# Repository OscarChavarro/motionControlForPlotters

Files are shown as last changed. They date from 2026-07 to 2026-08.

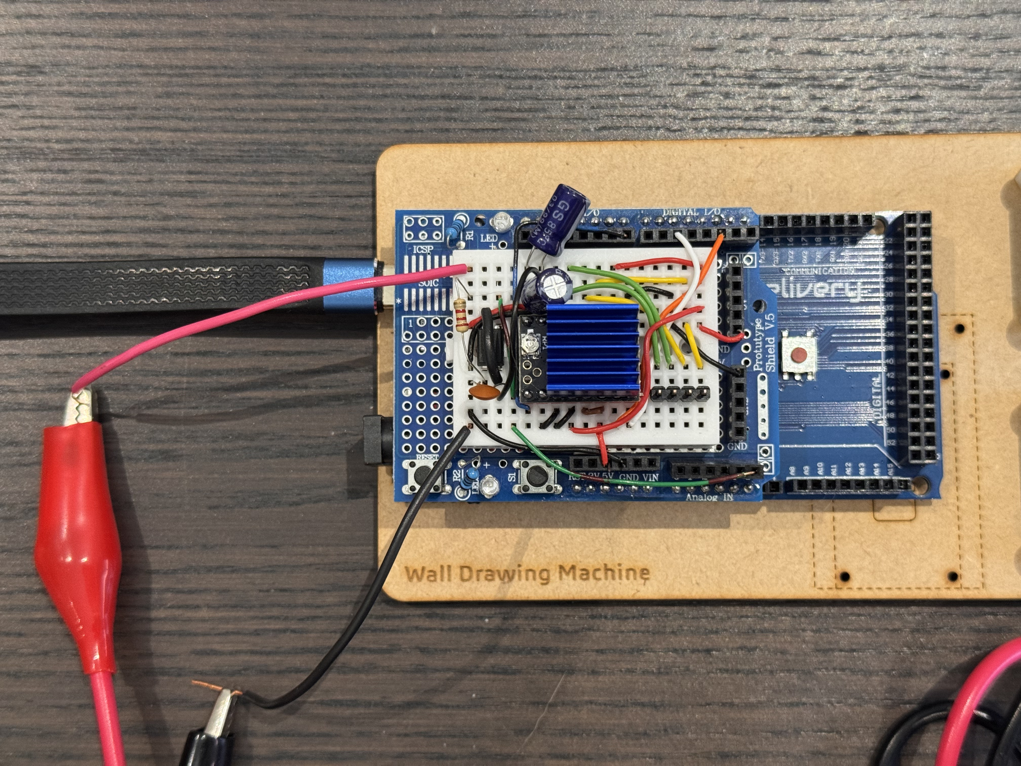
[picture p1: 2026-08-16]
platform/arduinoStepMotorsXYController/doc/prototypeShield.jpg

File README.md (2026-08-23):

# Motion Control for Plotters

Motion Control for Plotters is a firmware-oriented C++ project for building a portable motion-control core and platform-specific embedded targets for plotter hardware. The portable core and AVR target use C++17; the ESP32 target uses C++20.

The current codebase is split into two main areas:

- `motionControlCore`: reusable platform-independent motion logic.
- `platform`: hardware-specific firmware entry points and device wrappers.

At this stage, the core contains 2D rasterization, stepper-motor modeling, and a portable per-motor controller. The Arduino AVR target supplies the hardware clock, UART, power-supply sensing, and `STEP`/`DIR` pulse generation. The ESP32 target supplies a BLE serial endpoint that will later control servos. The Arduino's current repeating movement is a diagnostic program that will evolve into the generic controller.

## Core

`motionControlCore` currently provides:

- `Rasterizer2D`, a callback-based rasterization utility intended for plotter-oriented motion code.
- `StepperMotor`, the physical motor model and unit conversions between microsteps, rotations, and degrees.
- `StepperMotorController`, independent position, direction, speed, and trapezoidal-profile state for one motor.
- `StepperMotorDriver`, the platform boundary used by the controller to select direction and emit a step.
- `SystemClock`, `UartSerial`, `GpioLed`, and `ExternalPowerSupplyDetector`, portable HAL interfaces implemented by each target platform.

`UartSerial` also contains the reusable integer, fixed-point, voltage, and line
formatting used by telemetry. Platform implementations only provide UART
initialization and character input/output.

It supports:

- Drawing integer 2D lines with a Bresenham-style algorithm.
- Drawing polygon outlines by rasterizing each polygon edge.
- Filling polygons by emitting horizontal spans through a callback.

The rasterizer does not draw into a framebuffer. Instead, callers provide callbacks that receive generated points or spans. This keeps the core independent from any display, image, or hardware implementation and makes it suitable for later connection to motion planners, step schedulers, or other plotter backends.

## Platform

The implemented platform targets are:

- `platform/arduinoStepMotorsXYController`, AVR firmware built without the
  Arduino IDE.
- `platform/esp32ServoBLEController`, C++20 ESP-IDF firmware for an ESP-WROOM-32
  development board. It exposes a Nordic UART Service over BLE and only uses
  USB for flashing.

The Arduino target's platform-specific C++ code lives directly under `platform/arduinoStepMotorsXYController/src`.

It provides:

- `AvrSystemClock`: implements `SystemClock` using AVR Timer0 compare interrupts.
- `AvrUartSerial`: implements the primitive `UartSerial` operations using UART0.
- `AvrGpioLed`: implements `GpioLed` using the built-in board LED registers.
- `AvrExternalPowerSupplyDetector`: implements external motor-supply sensing through AVR ADC0.
- `AvrStepDirectionDriver`: maps Arduino digital pins to AVR registers and generates `STEP`/`DIR` signals.
- `main.cpp`: constructs AVR implementations, exposes them to the program through HAL references, declares the motor registry, and runs the current diagnostic motion program.

Adding a motor requires adding one entry to `STEPPER_MOTOR_PROGRAMS` in
`main.cpp`. The number of motors and all runtime arrays are derived from that
single registry. Every entry can use a different model, pin pair, electrical
timing, travel distance, and acceleration/cruise/deceleration times.

On the Mega 2560, the AVR driver supports digital pins D2-D53. With D0/D1
reserved for USB UART, this gives a theoretical wiring limit of 26 two-pin
motor drivers. Actual simultaneous motor count and speed remain constrained by
the current cooperative pulse generator and the 16 MHz CPU; timer-driven pulse
scheduling is a later phase.

Supported board presets are:

- `uno`
- `nano`
- `mega2560`

## Install

Prerequisites:

- CMake 3.22 or newer.
- `avr-gcc`.
- AVR binutils and runtime libraries.
- `avrdude` for uploading firmware to an Arduino board.
- `make` or another CMake-supported build tool.
- ESP-IDF 5.x and its ESP32 toolchain for the optional ESP32 firmware.

macOS:

```bash
brew tap osx-cross/avr;brew trust --formula osx-cross/avr/avr-gcc@9;brew trust osx-cross/avr;brew install avr-gcc avrdude
```

Ubuntu Linux:

```bash
sudo apt-get update
sudo apt-get install cmake gcc-avr avr-libc binutils-avr avrdude make
```

## Build

Configure the project from the repository root:

```bash
cmake -S . -B build
```

Build the reusable core and configure/build the Arduino firmware:

```bash
cmake --build build --target arduino_build
```

Generate the Arduino Intel HEX firmware:

```bash
cmake --build build --target arduino_hex
```

The generated firmware is written to:

```text
build/platform-arduinoStepMotorsXYController/arduinoStepMotorsXYController.hex
```

Build the ESP32 BLE firmware after activating ESP-IDF:

```bash
cmake --build build --target esp32_build
```

The ESP-IDF target defaults to `esp32`. Select another supported family member
when configuring the repository, for example:

```bash
cmake -S . -B build-h2 -DIDF_TARGET=esp32h2
cmake --build build-h2 --target esp32_build
```

You can also run
`platform/esp32ServoBLEController/scripts/compile.sh` directly. See that
platform's README for its BLE service UUIDs and setup details.

## Upload

Connect the Arduino board and configure the serial port if needed:

```bash
cmake -S . -B build -DARDUINO_BOARD=uno -DARDUINO_PORT=/dev/ttyACM0
cmake --build build --target arduino_upload
```

On macOS, the port will commonly look like `/dev/cu.usbmodem...` or `/dev/cu.usbserial...`.

Flash the ESP32 firmware through its temporary USB connection with:

```bash
cmake --build build --target esp32_flash
```

## Serial Monitor

Open the serial monitor through the CMake target:

```bash
cmake --build build --target arduino_monitor
```

The monitor target uses `pyserial` miniterm when available, then falls back to `picocom` or the repository's shell serial monitor.

## Configuration

The top-level CMake project exposes these platform options:

- `IDF_TARGET`: ESP-IDF target used by the BLE firmware (default `esp32`;
  for example, `esp32h2`).

- `ARDUINO_BOARD`: board preset, one of `uno`, `nano`, or `mega2560`.
- `ARDUINO_PORT`: serial/upload port.
- `ARDUINO_UPLOAD_BAUD`: optional upload baud override.
- `ARDUINO_MONITOR_BAUD`: optional serial monitor baud override.
- `ARDUINO_PROGRAMMER`: optional `avrdude` programmer override.
- `STEPPER_MOTOR_STEP_PIN`: X-axis diagnostic motor `STEP` pin (default D2).
- `STEPPER_MOTOR_DIRECTION_PIN`: X-axis diagnostic motor `DIR` pin (default D5).
- `STEPPER_MOTOR_Y_STEP_PIN`: Y-axis FS31W01 `STEP` pin (default D3).
- `STEPPER_MOTOR_Y_DIRECTION_PIN`: Y-axis FS31W01 `DIR` pin (default D6).
- `STEPPER_MOTOR_Y_DIRECTION_INVERTED`: inverts the Y `DIR` output in
  firmware (default `0`), without swapping motor wires.
- `STEPPER_MOTOR_Y_FULL_STEPS_PER_ROTATION`: Y-axis motor resolution in full
  steps (default 200).
- `STEPPER_MOTOR_Y_TRAVEL_ROTATIONS`: rotations for one direction of the Y
  test profile (default 2, matching X).
- `STEPPER_MOTOR_TRAVEL_ROTATIONS`: rotations in each forward/backward segment.

The Arduino subproject also accepts lower-level overrides such as `ARDUINO_MCU` and `ARDUINO_F_CPU` when a preset is not enough.

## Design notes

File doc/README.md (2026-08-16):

# Motion Control Platform Architecture Notes

## Project Vision

This project is not intended to be an Arduino sketch or a GRBL clone. The objective is to build a portable, modular motion-control framework capable of running on multiple embedded platforms while being driven by a sophisticated CAD backend.

Primary goals:

- C++-based architecture.
- No Arduino IDE.
- Git repository with CLI workflow.
- Portable core.
- Hardware Abstraction Layer (HAL).
- Binary communication protocol.
- Interrupt- and timer-based execution (no `delay()`).
- Closed-loop validation using computer vision.

## Target Platforms

- Arduino AVR (Mega/Uno family)
- ESP32
- Linux-based dual-core RISC-V development board (64 MB RAM)

The same motion core should execute on every platform, with only the HAL changing.

# Multiple device system

Every firmware integrated with the interactive console must implement the
`device` serial command. It must return exactly one line in this format:

```text
Device <hardware description>, Role <firmware role>
```

The hardware description identifies the board or hardware on which the
firmware runs. The role identifies the responsibility provided by that
firmware. For example, the current Arduino controller returns:

```text
Device arduino ATmega2650, Role XY steper motor controller
```

When started through `./scripts/runInteractive.sh`, the interactive console
enumerates all available USB serial ports, opens each one, and sends `device`.
It retains the connections that provide a valid device description and starts
only when it finds the expected device and role. If no expected firmware is
found, it exits with an English error message. This discovery contract allows
future console features to communicate with several role-specific devices at
the same time.

## Current Implementation Phase

The repository is currently building the infrastructure incrementally. The
Arduino program is diagnostic firmware, not the final motion-control protocol
or planner. Its repeating forward/backward movement exists to exercise motor
modeling, physical pin assignment, motion profiles, power gating, and
telemetry while those pieces are separated into reusable layers.

The current boundary is:

```text
main.cpp motor registry and diagnostic program
    -> portable HAL interfaces
        -> SystemClock, UartSerial, GpioLed,
           ExternalPowerSupplyDetector, StepperMotorDriver
    -> portable motion logic
        -> StepperMotorController (per-motor state and motion profile)
    -> AVR implementations created during platform initialization
        -> AvrSystemClock, AvrUartSerial, AvrGpioLed,
           AvrExternalPowerSupplyDetector, AvrStepDirectionDriver
```

The diagnostic program constructs each concrete `Avr*` object once and then
uses references to the corresponding core interface. This keeps application
logic independent from AVR headers and allows another platform to compose the
same logic with its own implementations.

`StepperMotor` describes one physical motor installation: motor reference,
motor type, full steps per rotation, configured microstepping, and its `STEP`
and `DIR` pin assignment. Each registered motor owns an independent driver and
controller state, including position, direction, speed, profile clock, and
fractional-step accumulator.

On an Arduino Mega 2560, reserving D0 and D1 for UART leaves D2-D53 available
for up to 26 two-pin `STEP`/`DIR` motor drivers. The AVR platform driver maps
that complete digital-pin range. This is a pin-count limit only: the present
cooperative loop emits pulses with short blocking waits. A timer/interrupt
step scheduler is still required before simultaneous high-rate operation can
be guaranteed for many motors.

## Development Environment

- VS Code
- PlatformIO for embedded builds
- Git
- C++
- Optional CMake for the reusable core

Suggested repository layout:

```text
motion-core/
firmware-avr/
firmware-esp32/
firmware-riscv/
host/
docs/
tests/
```

The reusable motion core should remain independent from PlatformIO.

## Motion Architecture

```text
CAD Kernel
    ↓
Hidden Line Removal
    ↓
Motion Backend
    ↓
Binary Protocol
    ↓
Motion Controller
    ↓
Motion Planner
    ↓
Rasterization (Bresenham)
    ↓
Step Scheduler
    ↓
HAL
    ↓
Stepper Drivers
```

## PC Responsibilities

The PC already implements:

- Winged-edge B-Rep kernel
- Euler operators
- Splitting operations
- Boolean operations
- Camera projection
- Quantitative observability
- Appel hidden-line algorithm

The CAD kernel generates projected 2D primitives that will drive the plotter.

The firmware never manipulates CAD topology.

## Firmware Responsibilities

The firmware is responsible for:

- Parsing binary packets
- Queueing primitives
- Motion planning
- Rasterization
- Pulse generation
- Sensor handling
- Safety

## Primitive-Based Protocol

The protocol transports graphical primitives rather than low-level motor commands.

Examples:

- MOVE_TO
- LINE_TO
- ARC
- BEZIER
- PEN_UP
- PEN_DOWN
- HOME
- STOP
- PANIC

The protocol is binary, versioned, little-endian, and transport-independent (USB, TCP, BLE, Wi-Fi, UART).

Each command should include a transaction ID to correlate firmware execution with camera observations.

## Rasterization

The firmware should execute Bresenham internally.

Curves should be converted into line segments before Bresenham.

Examples:

Bezier
→ Adaptive subdivision
→ Line segments
→ Bresenham

Arc
→ Arc subdivision
→ Line segments
→ Bresenham

## Motion Generation

The firmware should use:

- Hardware timers
- Interrupts
- State machines
- Pulse scheduling

The final scheduler must not use blocking delays. The current diagnostic AVR
driver still uses short blocking waits while emitting each pulse; replacing it
with timer/interrupt scheduling is part of the planned platform work.

Future extensions:

- Command-driven trapezoidal profiles (a repeating diagnostic profile exists)
- S-curve acceleration
- Look-ahead planner

## Safety

Firmware states:

- BOOT
- INITIALIZING
- IDLE
- READY
- RUNNING
- PAUSED
- HOMING
- ERROR
- PANIC

PANIC immediately:

- Stops motion timers
- Clears queues
- Disables drivers
- De-energizes motors

Recovery requires RESET followed by HOMING.

## Limit Switches

Support:

- Home switches
- Safety switches
- Probe inputs
- Soft limits

Soft limits should exist both in the PC and firmware.

## Events

Firmware should report binary events instead of text:

- READY
- HOME_COMPLETE
- MOTION_COMPLETE
- LIMIT_REACHED
- EMERGENCY_STOP
- PANIC
- POSITION_LOST

## Closed-Loop Vision

Unlike traditional CNC controllers, this project includes vision-based validation.

The PC contains:

- OpenCV
- High-speed camera
- AprilTag fiducial tracking

Workflow:

1. PC sends a primitive.
2. Firmware executes it.
3. Camera measures the physical position.
4. PC validates the result.
5. PC either:
   - continues,
   - sends a correction,
   - retries,
   - or enters PANIC mode.

This creates a distributed control system where the firmware guarantees deterministic execution while the PC closes the feedback loop through computer vision.

## Long-Term Goal

Develop a modern, portable motion-control platform that cleanly separates:

- CAD
- Communication
- Motion planning
- Hardware abstraction
- Safety
- Vision feedback

The architecture should scale from AVR to ESP32 and Linux-based RISC-V systems without changing the core motion logic.

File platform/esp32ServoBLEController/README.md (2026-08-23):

# ESP32 Servo BLE Controller

ESP-IDF firmware for ESP32-family devices with Bluetooth Low Energy support.
The default target is the classic dual-core ESP32 development board based on
the ESP-WROOM-32 module (including the AZDelivery clone). USB is only used to
flash the firmware. Runtime communication uses Bluetooth Low Energy.

The device name is `ESP-WROOM-32` and it implements the Nordic UART Service
(NUS). GPIO2 also drives a status LED, alternating between one second off and
one second on while the firmware is running. GPIO22 is configured as a 50 Hz
LEDC PWM output for the connected servo; `motorPosition` values from 0 to 255
are mapped to 1000 us to 2000 us servo pulses.

| Purpose | UUID | Properties |
|---|---|---|
| Service | `6E400001-B5A3-F393-E0A9-E50E24DCCA9E` | Primary service |
| Client to ESP32 (RX) | `6E400002-B5A3-F393-E0A9-E50E24DCCA9E` | Write, write without response |
| ESP32 to client (TX) | `6E400003-B5A3-F393-E0A9-E50E24DCCA9E` | Notify |

After connecting, the client must subscribe to TX notifications. The firmware
then sends `firmware boot`. Bytes written to RX are parsed as ASCII commands;
clients can send one complete command per BLE write or terminate streamed
commands with `\r` or `\n`. Long output is split into chunks that fit the
negotiated BLE ATT MTU.

Initial BLE commands:

```text
hardware
. [<id>]
servo <id> <position>
test off|on
```

`hardware` lists the GPIO22 servo PWM output and the GPIO2 heartbeat LED.
`.` prints the current servo telemetry summary. `. 0` prints the CSV status
for the servo PWM element and `. 1` prints the CSV status for the heartbeat
LED element. `servo 0 <position>` sets the servo resource to a value from 0 to
255 and disables the demo movement. `test off` stops the demo movement, while
`test on` enables it again.

## Requirements

- ESP-IDF 5.x with the toolchain for the selected `IDF_TARGET` installed
- CMake 3.22 or newer
- Ninja
- An FTDI UART adapter and a stable board power source for the current hardware

The scripts automatically discover installations made by EIM under
`~/.espressif`, common legacy installations under `~/esp/esp-idf` and
`~/esp-idf`, or an SDK selected explicitly through `IDF_PATH`.

## Build

From this directory:

```bash
./scripts/compile.sh
```

`IDF_TARGET` defaults to `esp32`. Set it to build for another supported chip;
each target uses a separate build directory and SDK configuration:

```bash
IDF_TARGET=esp32h2 ./scripts/compile.sh
```

From a configured repository root build, the equivalent target is:

```bash
cmake --build cmake-build-host-debug --target esp32_build
```

For a repository-level build, select the target while configuring CMake:

```bash
cmake -S . -B cmake-build-h2 -DIDF_TARGET=esp32h2
cmake --build cmake-build-h2 --target esp32_build
```

The BLE task uses core 1 on multicore configurations and no explicit affinity
on single-core configurations. GPIO2 remains the default status LED pin; board
variants whose onboard LED uses another GPIO still require a pin adjustment.

## Flash through USB

The current board's onboard CP210x bridge is damaged. Connect an FTDI adapter
to UART0 RX/TX and use `/dev/cu.usbserial-1120`. Cross the data lines (ESP32 TX0
to FTDI RX and ESP32 RX0 to FTDI TX), connect their grounds, and power the ESP32
from a stable source. Do not rely on a small FTDI adapter's 3.3 V output to
power the board.

The damaged USB/reset circuitry on this particular board also makes its RST
button unreliable: EN measures about 3.28 V at rest but only falls to about
1.3 V while RST is held. A valid manual reset is obtained by briefly connecting
EN directly to GND and then releasing it.

An external normally-open reset button can be installed as follows. The button
must connect EN to GND, never directly to 3.3 V. The capacitor is optional; if
the damaged automatic-reset branch continues driving EN, isolate that branch
before adding a stronger pull-up.

```text
                         ESP32
  +3.3 V ----[ 4.7 kΩ ]----+---- EN / CHIP_PU
                            |
                            +----||---- GND
                            |   100 nF
                            |
                         [ RESET ]
                      normally open
                            |
                           GND
```

To enter the immutable ROM bootloader:

1. Connect GPIO0 to GND.
2. Briefly connect EN to GND, then release EN.
3. Keep GPIO0 low while the flash tool connects and performs its operations.
4. Run the flash command below.

```bash
./scripts/send.sh /dev/cu.usbserial-1120
```

The script builds the project, writes the bootloader, partition table and
application, and then runs an independent `verify_flash` comparison against all
three generated binaries. A successful operation contains three `verify OK
(digest matched)` messages. It deliberately finishes with `--after no_reset`
so this board remains in the ROM bootloader instead of using its unreliable
reset circuitry. The default transfer rate is the conservative 115200 baud
because this board stopped responding during a 460800-baud transfer. Set
`ESP32_BAUD` explicitly only when using a known-stable UART connection. The
script also waits indefinitely for the manual ROM synchronization by default;
set `ESP32_CONNECT_ATTEMPTS` to a positive value to impose a retry limit.
Both write and verification use `--before no_reset`; EN and GPIO0 must be
operated manually because DTR/RTS reset sequences are unreliable on this board.

After verification, disconnect GPIO0 from GND, remove power for at least two
seconds, and restore power. A cold power cycle has been more reliable than the
board's RST button. A normal UART boot starts with:

```text
boot:0x13 (SPI_FAST_FLASH_BOOT)
```

The following output means GPIO0 was sampled low and the application will not
run:

```text
boot:0x3 (DOWNLOAD_BOOT...)
waiting for download
```

Repeated `rst:0x1 (POWERON_RESET)` messages indicate instability on EN or the
power/reset circuitry rather than a firmware crash.

Set `ESP32_PORT=/dev/...` or pass the port as the first argument to avoid
interactive port selection:

```bash
./scripts/send.sh /dev/cu.usbserial-0001
```

For non-`esp32` targets, the script selects the matching esptool chip, uses the
target-generated flash layout, and enables normal automatic reset handling:

```bash
IDF_TARGET=esp32h2 ./scripts/send.sh /dev/cu.usbmodem0001
```

The equivalent root target is `esp32_flash`. Disconnecting USB after flashing
does not affect BLE operation as long as the board has another power source.

## Hardware diagnosis from the MicroPython test

The following facts were verified on this specific board during bring-up:

- The chip is an ESP32-D0WDQ6 revision 1.0 with two cores and 4 MB of flash.
- The ROM bootloader, SPI flash and UART0 work. Written images passed an
  independent digest comparison against the source binaries.
- MicroPython 1.28.0 booted successfully and reached its UART REPL.
- A minimal `main.py` could drive GPIO2 high and blink an attached LED once it
  was explicitly started.
- GPIO2 read back as high and illuminated the LED, so the pin and LED wiring
  are operational.
- A cold power cycle with GPIO0 high produced `SPI_FAST_FLASH_BOOT` and allowed
  MicroPython to start `main.py` automatically.
- The unreliable EN/RST and GPIO0 boot-strapping behavior explains the earlier
  failures to observe either the GPIO2 heartbeat or BLE advertisements. Those
  failures do not by themselves implicate FreeRTOS, NimBLE or the C++ image.

At the end of this diagnostic test, MicroPython occupies the flash and the C++
firmware must be flashed again before testing BLE.

## Returning to the C++ firmware

Flashing the C++ image will overwrite MicroPython, including its filesystem and
`main.py`. This does not remove the ESP32 ROM bootloader: the ROM loader is part
of the chip and remains available regardless of what is stored in SPI flash.
Therefore a broken or non-booting C++ application can always be replaced by
entering download mode with GPIO0 and EN as described above.

Use this recovery and activation plan:

1. Build the C++ firmware with `./scripts/compile.sh`.
2. Enter the ROM bootloader using GPIO0 and a direct EN-to-GND reset.
3. Run `./scripts/send.sh /dev/cu.usbserial-1120` and require all three
   `verify OK` results before proceeding.
4. Disconnect GPIO0 from GND.
5. Remove power for at least two seconds and restore it; do not depend on the
   faulty RST button or on `esptool run` to launch the application.
6. Confirm the GPIO2 one-second heartbeat first, then scan for the BLE device
   name and Nordic UART Service UUID.
7. If the heartbeat is absent, capture UART0 during another cold power cycle.
   Diagnose the ROM boot mode before changing any C++ or FreeRTOS code.

## Clean

```bash
./scripts/clean.sh
```

This removes the ESP-IDF build tree plus generated `sdkconfig` files. The root
CMake target is `esp32_clean`.

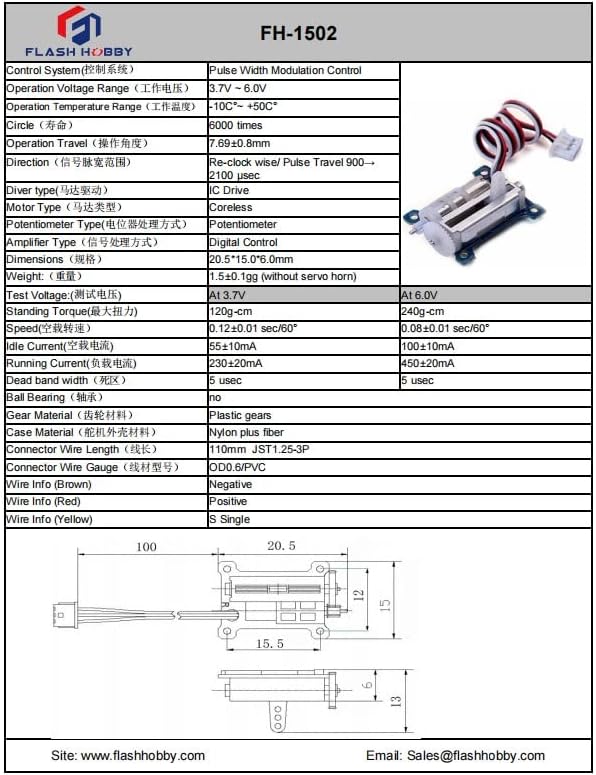
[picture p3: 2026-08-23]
doc/references/electronicsElements/motors/flashHobby_FH1502.jpg

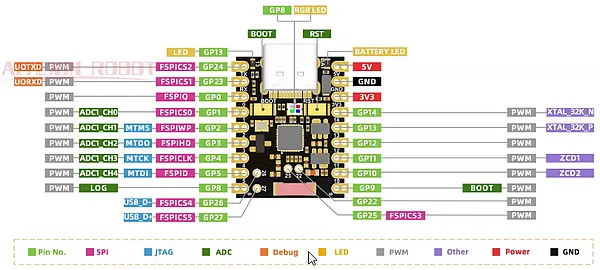
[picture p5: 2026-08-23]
doc/references/electronicsElements/microControllerBoards/esp32_h2.png

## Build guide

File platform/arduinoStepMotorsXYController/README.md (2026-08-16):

# Arduino Step Motors XY Controller

Firmware target for an Arduino UNO or Mega2560-based XY step motor controller.

# Elements used

## Artillery D42HSA5401-23B stepper motor

NEMA17 "pancake" bipolar stepper motor, used for the Artillery Sidewinder
X1/X2 and Genius 3D printer extruders.

| Spec | Value |
|---|---|
| Model | D42HSA5401-23B |
| Motor type | NEMA17 bipolar hybrid stepping motor, "pancake" (short body) |
| Step angle | 1.8 degrees (200 steps/revolution) |
| Rated current | 0.8 A |
| Holding torque | 0.12 N.m |
| Shaft diameter | 5.0 mm |
| Body length | 22 mm |

Source: [Artillery Sidewinder X1/X2 Genius Extruder Nema17 Stepper Motor (D42HSA5401-23B)](https://www.amazon.es/Artillery-Sidewinder-Extrusor-Stepper-D42HSA5401-23B/dp/B0B26XPB9P)

## TMC2209 V2.0 stepper driver (generic clone)

Generic "TMC2209 V2.0" driver module, pin-compatible with the A4988/DRV8825
socket footprint, used to replace the A4988 driver.

| Spec | Value |
|---|---|
| Model | TMC2209 V2.0 (generic clone, sold as a 2-piece pack) |
| Driver chip | TRINAMIC/Analog Devices TMC2209 |
| Sense resistor | 0.11 ohm (R110) |
| Max current | 1.77 A RMS at VREF=2.5V (practical modules typically limited to ~1.2 A RMS) |
| Microstepping | Up to 1/256 via MicroPlyer interpolation, MS1/MS2 pins select 1/8, 1/16, 1/32, 1/64 in standalone mode |
| Chopper modes | StealthChop2 (silent) and SpreadCycle, selectable via SPREAD pin |
| Control interface | STEP/DIR, single-wire UART, analog VREF current scaling |

Source: [2 piezas de controladores de motor paso a paso TMC2209 V2.0](https://www.amazon.es/dp/B0D6R7YCRT)

## AZDelivery AZ-MEGA2560 microcontroller board (Arduino Mega 2560 clone)

Arduino Mega 2560-compatible board used as the firmware target.

| Spec | Value |
|---|---|
| Model | AZDelivery AZ-MEGA2560-Board with USB-C |
| Microcontroller | ATmega2560 |
| Flash memory | 256 KB (8 KB used by bootloader) |
| SRAM | 8 KB |
| EEPROM | 4 KB |
| Digital I/O pins | 54 (14 usable as PWM) |
| Analog inputs | 16 |
| UARTs | 4 |
| Clock speed | 16 MHz |
| USB interface | USB-C, CH340 converter |
| External power input | 5.5 x 2.1 mm jack, 6-15V (7-12V recommended) |

Source: [AZDelivery AZ-MEGA2560 Board Mikrokontroller mit USB-C Anschluss](https://www.amazon.es/dp/B0DHY38ZB1)

## LOMVUM T28B digital multimeter

Used for VREF calibration and for driver/motor temperature checks, via its
K-type thermocouple probe.

| Spec | Value |
|---|---|
| Model | LOMVUM T28B |
| Type | Auto-ranging digital multimeter, True RMS, 6000 counts |
| DC voltage | Up to 1000 V |
| AC voltage | Up to 750 V |
| AC/DC current | Up to 10 A |
| Capacitance | Up to 100 mF |
| Temperature probe | K-type thermocouple |
| Safety rating | CAT III 1000V / CAT IV 600V |
| Display | 3.0" backlit LCD, data hold |

Source: [LOMVUM T28B Automatic Digital Multimeter](https://www.amazon.es/dp/B07FXH2R5M)

## RUZIZAO regulated bench power supply

Adjustable bench power supply used to provide the external `VMOT` motor
supply voltage, with digital display, rotary encoder setpoint controls, and a
built-in USB fast-charging output.

| Spec | Value |
|---|---|
| Model | RUZIZAO Regulated Power Supply |
| Output voltage | 0-30 V, adjustable |
| Output current | 0-10 A, adjustable |
| USB output | 18 W fast charging |
| Protection | OCP (over-current), OVP (over-voltage) |
| Display | Digital, with rotary encoder setpoint controls |

Source: [RUZIZAO Regulated Power Supply 30V 10A](https://www.amazon.es/dp/B0DMW7M7PS)

Fritzing part: no exact match found; the closest available part is the
community-contributed [Hanmatek HM305 bench power supply](https://forum.fritzing.org/t/dc-power-supply/20680)
(`hanmatek-HM305.fzpz`, direct download at
[forum.fritzing.org/uploads/short-url/165qJwjxYqDpQ5ndsKmUOZ4f1SG.fzpz](https://forum.fritzing.org/uploads/short-url/165qJwjxYqDpQ5ndsKmUOZ4f1SG.fzpz)),
which shares the same boxed form factor: digital display, voltage/current
adjustment knobs, and DC output terminals. Import it via **Part > Import...**
in Fritzing.

# Arduino PINOUT

| Pin | UNO | MEGA2560 | Direction | Use |
|---|---|---|---|---|
| 2 | D2 / PD2 | D2 / PE4 | Output | A4988/TMC2209 STEP input |
| 3 | D3 / PD3 | D3 / PE5 | Output | Y-axis A4988 STEP input |
| 5 | D5 / PD5 | D5 / PE3 | Output | A4988/TMC2209 DIR input |
| 6 | D6 / PD6 | D6 / PH3 | Output | Y-axis A4988 DIR input |
| 8 | D8 / PB0 | D8 / PH5 | Output | Shared motor driver EN input (active low; CNC Shield X/Y/Z EN) |
| 13 | D13 / PB5 | D13 / PB7 | Output | Testing LED |
| A5 | ADC5 / PC5 | ADC5 / PF5 | Analog input | External power supply unit detection via voltage divider from VMOT |

This pinout matches the X-axis socket of a Protoneer-compatible Arduino CNC
Shield V3 (`doc/references/electronicsElements/arduino-cnc-shield-protoneer.pdf`):
STEP=D2, DIR=D5, and the shared EN=D8. The driver receives one motor step on
each rising edge of `STEP`. The `DIR` signal selects the direction used by the
next `STEP` rising edge. `EN` is active low and shared by every axis on the
shield: driving it LOW enables all motor drivers at once, HIGH disables them
all, regardless of each motor's own STEP/DIR state. `D0` and `D1` stay free
for the USB serial console.

The X registry entry uses a `D42HSC4409B-23B` motor driven by an Artillery
`FS31W01 191202` module in STEP/DIR mode. The second entry is wired to the
CNC Shield Y socket: STEP=D3 and DIR=D6; it uses the same motor and driver
identification. Both drivers are configured at 1/16 microstepping, so each
200-step motor reports 3200 microsteps per rotation. Their test segments are
two rotations. The shared D8 enable line controls both X and Y drivers.

The PSU voltage divider uses `A5` rather than `A0` on purpose: on the CNC
Shield, `A0`-`A3` are committed to Abort/Feed Hold/Cycle Start/Coolant, and
`A0` specifically already has the shield's own 10k pull-up populated, which
would bias this divider's reading if reused. `A4`/`A5` are documented as
unused/reserved on the shield, so `A5` is free of both the semantic and the
electrical conflict.

`AvrStepDirectionDriver` supports D2-D13 on UNO/Nano and D2-D53 on Mega
2560. The program rejects D0/D1 because this firmware reserves them for UART,
and it rejects repeated pins across registered motors. Consequently, the Mega
has a theoretical maximum of 26 two-pin motor drivers. The current
cooperative, blocking pulse implementation does not yet guarantee that 26
motors can be driven simultaneously at useful rates.

The first stepper motor and its controller are configured with:

```bash
-DSTEPPER_MOTOR_STEP_PIN=2
-DSTEPPER_MOTOR_DIRECTION_PIN=5
-DSTEPPER_MOTOR_Y_STEP_PIN=3
-DSTEPPER_MOTOR_Y_DIRECTION_PIN=6
-DSTEPPER_MOTOR_Y_DIRECTION_INVERTED=0
-DSTEPPER_MOTOR_Y_FULL_STEPS_PER_ROTATION=200
-DSTEPPER_MOTOR_Y_TRAVEL_ROTATIONS=2
-DMOTOR_DRIVER_ENABLE_PIN=8
-DSTEPPER_MOTOR_STEP_PULSE_MICROSECONDS=5
-DSTEPPER_MOTOR_DIRECTION_SETUP_MICROSECONDS=5
-DSTEPPER_MOTOR_TRAVEL_ROTATIONS=2
-DSTEPPER_MOTOR_ACCELERATION_MILLISECONDS=1000
-DSTEPPER_MOTOR_CRUISE_MILLISECONDS=8000
-DSTEPPER_MOTOR_DECELERATION_MILLISECONDS=1000
```

The example motion profile is a repeating trapezoid. In each direction the
motor moves 2 rotations in 10 seconds: 1 second accelerating, 8 seconds at
constant speed, and 1 second decelerating. The next 10-second segment repeats
the same trapezoid backward for 2 rotations. With the default 200-step
`Artillery D42HSA5401-23B` motor and the A4988 configured for 1/16
microstepping, 2 rotations map to 6400 microsteps and require a calculated
maximum profile speed of about 0.222 rotations per second.
The firmware stores motor definitions in the `STEPPER_MOTOR_PROGRAMS` table in
`src/main.cpp`. Adding one table entry automatically adds its platform driver,
portable controller, initialization, validation, update, and telemetry state.
Each table entry may have independent model, pins, pulse timings, travel, and
trapezoid timings.

The reusable `StepperMotorController` and the `SystemClock`, `UartSerial`,
`GpioLed`, `ExternalPowerSupplyDetector`, `MotorDriverEnable`, and
`StepperMotorDriver` interfaces live in `motionControlCore`. Their concrete
implementations in this target are named `AvrSystemClock`, `AvrUartSerial`,
`AvrGpioLed`, `AvrExternalPowerSupplyDetector`, `AvrMotorDriverEnable`, and
`AvrStepDirectionDriver`. `main.cpp` creates these concrete objects during
initialization and uses the core interface types afterward.

The external power supply detector no longer measures a voltage: it reads a
`PC817` opto-isolator wired to `A5`, which reports only presence/absence of
the external `VMOT` supply.

```text
VMOT --/\/\/-- (1)PC817(2) -- GND      LED side: lit whenever VMOT is present
  2.2 kOhm

 5V (internal pull-up) --- A5 ---(3)PC817(4)--- GND   Phototransistor side
```

Wiring:

| PC817 pin | Connects to | Role |
|---|---|---|
| 1 (LED anode) | `VMOT` through a `2.2 kOhm` series resistor | Lights the opto LED whenever the external supply is present |
| 2 (LED cathode) | `GND` | LED return path |
| 3 (phototransistor) | `A5` | Pulled toward `GND` while the LED is lit |
| 4 (phototransistor) | `GND` | Phototransistor return path |

`A5` is configured as a digital input with the ATmega's internal pull-up
enabled, so it idles HIGH (~5V) with no external pull-up resistor needed.
Reading is **inverted logic**: `LOW` (~0V) means the opto LED is lit and the
external supply is present; `HIGH` (~5V, pulled up) means it is absent. This
also sidesteps the analog-divider conflict with the CNC Shield's `A0`-`A3`
pins discussed above: `A5` here just needs a clean digital HIGH/LOW, not an
analog measurement.

Since there is no measured voltage anymore, the millivolt-returning methods
on `AvrExternalPowerSupplyDetector` (`readAnalogInputMilliVolts`,
`readExternalSupplyMilliVolts`, `filteredExternalSupplyMilliVolts`) report a
nominal value instead of a measurement: `EXTERNAL_VOLTAGE_PSU * 1000` when
present, `0` when absent. This keeps the existing telemetry, `EVENT
PSU=READY|LOST VMOTOR=<voltage>V` line, and `PSU,<ON|OFF>,<voltage>,...` CSV
format unchanged, even though `<voltage>` is now a configured nominal value
rather than something actually measured.

| Variable | Default | Used for |
|---|---:|---|
| `EXTERNAL_VOLTAGE_PSU` | `24` | Nominal external power supply voltage, in volts, reported when the opto-isolator detects `VMOT` present |
| `PSU_NOT_FOUND_ERROR_PRINTING_TIME_INTERVAL` | `5000` | Minimum interval between missing-PSU error messages, in milliseconds |

The nominal PSU voltage is configured at CMake level with:

```bash
-DEXTERNAL_VOLTAGE_PSU=24
```

The missing-PSU error print interval is configured in milliseconds with:

```bash
-DPSU_NOT_FOUND_ERROR_PRINTING_TIME_INTERVAL=5000
```

At runtime, `AvrExternalPowerSupplyDetector` samples the digital `A5` reading
every 10 ms and requires 10 consecutive consistent samples (100 ms) before
flipping `isExternalPowerSupplyAvailable()`, debouncing the opto-isolator's
transition instead of filtering a measured voltage against a threshold.

Confirmed supply transitions produce a concise event containing the nominal
voltage value:

```text
EVENT PSU=READY VMOTOR=<voltage>V
EVENT PSU=LOST VMOTOR=<voltage>V
```

## Motor driver enable (`motorDriverEnabled`)

The PSU element also models a `motorDriverEnabled` flag, backed by
`MOTOR_DRIVER_ENABLE_PIN` (`D8` by default): the shared, active-low `EN` line
that every motor driver on the CNC Shield listens to at once.

- The flag defaults to `true`.
- The pin is only actually driven active (LOW, drivers powered) when **both**
  the flag is `true` **and** the external power supply is present. With no
  PSU, the drivers are always disabled regardless of the flag: there is
  nothing safe to power them from.
- With a PSU present, the flag lets the user (or the application, e.g. a
  panic button) turn the drivers off on demand, independent of PSU state.
- At boot, before the firmware has decided anything, the pin is held HIGH
  (disabled) as the safe default.

The flag is controlled with:

```text
motordriver <id> enable|disable
```

where `<id>` is the PSU element's id (the same id printed by `hardware` and
used with `get <id>`). `get <id>`/`. <id>` on the PSU element reports the flag
as an extra CSV field: `PSU,<ON|OFF>,<voltage>,<motorDriverEnabled 0|1>`.
`test <id> enable` and `steps <id> <n> <speed>` on a motor element both
report `Error: motor driver disabled.` and do nothing while the combined
enable state is off.

The firmware also emits diagnostic telemetry every 500 ms:

```text
VMOTOR: <filtered-voltage>V PSU: <OK|OFF> Motor <n> Dir: <F|R> Position: [rotation <n>, ]<angle> degrees Speed: <rotations-per-second> rps <degrees-per-second> deg/s
```

The firmware also accepts serial commands over the same UART, listed by
sending `help`:

```text
  . [<id>]  Print telemetry, or one element with an id.
  help  Show the list of available commands.
  hardware  List hardware elements by pin, tagged [id].
  get <id>  Print status of one hardware element.
  console enable  Enable periodic console output.
  console disable Disable periodic console output.
  test <id> enable|disable  Toggle test movement for element <id>.
  motordriver <id> enable|disable  Toggle the shared motor driver enable line (PSU element <id>).
  steps <id> <n> <speed>  Move motor <id> by n steps at speed steps/s (blocking; test must be disabled).
```

Every hardware element (each stepper motor, then the power supply detector)
gets a stable numeric id, assigned in the order printed by `hardware`. The
`test` command starts/stops the repeating back-and-forth trapezoid
independently for each motor id, so several motors can be exercised on their
own. `get <id>` and `. <id>` report one element's status as CSV
(`MOTOR,<F|R>,<speed>,<position>,<testEnabled>` or
`PSU,<ON|OFF>,<voltage>,<motorDriverEnabled 0|1>`); `.` with no id prints the
full human-readable telemetry line instead.

`steps <id> <n> <speed>` moves motor `<id>` by exactly `n` microsteps
(positive forward, negative backward, `n != 0`) paced at `speed` microsteps
per second (`speed > 0`), pulsing the driver directly instead of running the
trapezoid profile. Pacing is done with a busy-wait delay
(`StepperMotorDriver::waitMicroseconds`, backed by `avr-libc`'s `_delay_us`)
between pulses rather than the interrupt-driven `SystemClock`: `SystemClock`
only resolves `millis()`, which is far too coarse to space out steps a few
hundred microseconds apart, while `_delay_us` is a cycle-counted loop
calibrated against the compile-time `F_CPU`, so it gives accurate real
microsecond delays as long as `F_CPU` matches the board (which the board
presets already guarantee). This is safe here specifically because the
command is meant to block: there is no background work this firmware needs
to keep running (steps, PSU sampling, telemetry) while a manual jog is in
progress.

The command is blocking end-to-end: the firmware does not read or process
any other command until all `n` steps have been emitted, so it is not
interruptible. It only runs when that motor's `test` is disabled (motor in
SUSTAIN, not running the automatic back-and-forth movement), the motor's
pins are valid, and the external power supply is available; otherwise it
prints an error and does nothing.

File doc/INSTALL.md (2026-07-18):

# Instalación y uso del entorno AVR en Linux

Este repositorio usa `CMake` como orquestador y `avr-gcc` para compilación cruzada de firmware AVR escrito en C++17. El flujo genera un `.elf` y un `.hex` para Arduino, sin depender del Arduino IDE.

## Requisitos base

- `cmake` 3.22 o superior
- `avr-gcc`
- `avr-libc`
- `binutils-avr`
- `make` o `ninja`
- `avrdude` para carga por USB

## Paquetes comunes por distribución

### Debian / Ubuntu

```bash
sudo apt update
sudo apt install cmake gcc-avr avr-libc binutils-avr avrdude make
```

### Fedora

```bash
sudo dnf install cmake avr-gcc avr-libc avr-binutils avrdude make
```

### Arch Linux

```bash
sudo pacman -S cmake avr-gcc avr-libc avrdude make
```

## Compilación del firmware Arduino

Desde la raíz del monorepo:

```bash
cmake -S . -B build
cmake --build build --target arduino_hex
```

El `.hex` queda en:

```text
build/platform-arduinoStepMotorsXYController/arduinoStepMotorsXYController.hex
```

## Parámetros configurables

La configuración Arduino se controla con variables CMake:

- `ARDUINO_BOARD`: `uno`, `nano`, `mega2560`
- `ARDUINO_PORT`: por ejemplo `/dev/ttyACM0` o `/dev/ttyUSB0`
- `ARDUINO_UPLOAD_BAUD`: velocidad para `avrdude`
- `ARDUINO_MONITOR_BAUD`: velocidad del monitor serial
- `ARDUINO_PROGRAMMER`: programador `avrdude` (`arduino`, `wiring`, etc.)
- `ARDUINO_MCU`: override directo del microcontrolador AVR
- `ARDUINO_F_CPU`: override directo de frecuencia de CPU

Ejemplo:

```bash
cmake -S . -B build \
  -DARDUINO_BOARD=mega2560 \
  -DARDUINO_PORT=/dev/ttyACM0 \
  -DARDUINO_MONITOR_BAUD=115200
cmake --build build --target arduino_hex
```

## Carga por USB con avrdude

Si `avrdude` está instalado:

```bash
cmake --build build/platform-arduinoStepMotorsXYController --target arduinoStepMotorsXYControllerUpload
```

## Monitor serial por CLI

Si el entorno tiene `pyserial`, el target `arduinoStepMotorsXYControllerMonitor` usa:

```bash
python3 -m serial.tools.miniterm <puerto> <baud>
```

Si no, el build intenta usar `picocom` o el monitor serial shell del repositorio.

## Permisos de puerto serie

En muchas distribuciones el usuario debe pertenecer a `dialout` o grupo equivalente:

```bash
sudo usermod -aG dialout $USER
```

Después cierra sesión y vuelve a entrar.

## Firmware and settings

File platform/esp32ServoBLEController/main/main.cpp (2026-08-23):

#include <stdint.h>
#include <stdio.h>
#include <string.h>
#include <stdarg.h>

#include "freertos/FreeRTOS.h"
#include "freertos/semphr.h"
#include "freertos/task.h"
#include "driver/gpio.h"
#include "driver/ledc.h"
#include "esp_err.h"
#include "host/ble_hs.h"
#include "host/ble_uuid.h"
#include "nimble/nimble_port.h"
#include "nimble/nimble_port_freertos.h"
#include "nvs_flash.h"
#include "os/os_mbuf.h"
#include "services/gap/ble_svc_gap.h"
#include "services/gatt/ble_svc_gatt.h"

static constexpr char DEVICE_NAME[] = "ESP-WROOM-32";
static constexpr char ADVERTISED_NAME[] = "ESP-WROOM-32";
static constexpr char BOOT_MESSAGE[] = "firmware boot\r\n";
static constexpr uint16_t INVALID_CONNECTION_HANDLE = 0xffff;
static constexpr size_t MAX_RECEIVED_MESSAGE_SIZE = 512;
static constexpr size_t COMMAND_BUFFER_SIZE = 64;
static constexpr gpio_num_t STATUS_LED_GPIO = GPIO_NUM_2;
static constexpr gpio_num_t MOTOR_PWM_GPIO = GPIO_NUM_22;
static constexpr ledc_mode_t MOTOR_PWM_MODE = LEDC_LOW_SPEED_MODE;
static constexpr ledc_timer_t MOTOR_PWM_TIMER = LEDC_TIMER_0;
static constexpr ledc_channel_t MOTOR_PWM_CHANNEL = LEDC_CHANNEL_0;
static constexpr ledc_timer_bit_t MOTOR_PWM_RESOLUTION = LEDC_TIMER_14_BIT;
static constexpr uint32_t MOTOR_PWM_FREQUENCY_HZ = 50;
static constexpr uint32_t MOTOR_PWM_FRAME_MICROSECONDS = 1000000UL /
    MOTOR_PWM_FREQUENCY_HZ;
static constexpr uint32_t MOTOR_PWM_MAX_DUTY =
    (1UL << static_cast<uint32_t>(MOTOR_PWM_RESOLUTION)) - 1UL;
static constexpr uint32_t SERVO_MIN_PULSE_MICROSECONDS = 1000;
static constexpr uint32_t SERVO_MAX_PULSE_MICROSECONDS = 2000;
static constexpr uint16_t SERVO_ELEMENT_ID = 0;
static constexpr uint16_t LED_ELEMENT_ID = 1;
static constexpr TickType_t STATUS_LED_INTERVAL = pdMS_TO_TICKS(1000);

// Nordic UART Service UUIDs. UUID bytes are stored least-significant first by
// NimBLE, as required by BLE_UUID128_INIT.
static const ble_uuid128_t SERIAL_SERVICE_UUID = BLE_UUID128_INIT(
    0x9e, 0xca, 0xdc, 0x24, 0x0e, 0xe5, 0xa9, 0xe0,
    0x93, 0xf3, 0xa3, 0xb5, 0x01, 0x00, 0x40, 0x6e);
static const ble_uuid128_t SERIAL_RX_UUID = BLE_UUID128_INIT(
    0x9e, 0xca, 0xdc, 0x24, 0x0e, 0xe5, 0xa9, 0xe0,
    0x93, 0xf3, 0xa3, 0xb5, 0x02, 0x00, 0x40, 0x6e);
static const ble_uuid128_t SERIAL_TX_UUID = BLE_UUID128_INIT(
    0x9e, 0xca, 0xdc, 0x24, 0x0e, 0xe5, 0xa9, 0xe0,
    0x93, 0xf3, 0xa3, 0xb5, 0x03, 0x00, 0x40, 0x6e);

static uint8_t ownAddressType;
static uint16_t connectionHandle = INVALID_CONNECTION_HANDLE;
static uint16_t transmitValueHandle;
static bool notificationsEnabled;
static bool bootMessagePending;
static uint8_t motorPosition;
static bool motorPositionIncreasing = true;
static bool servoTestEnabled = true;
static portMUX_TYPE connectionStateLock = portMUX_INITIALIZER_UNLOCKED;
static SemaphoreHandle_t transmitMutex;
static SemaphoreHandle_t motorPositionMutex;

static char commandBuffer[COMMAND_BUFFER_SIZE];
static size_t commandLength;

static void startAdvertising();

static void sendSerialBytes(const uint8_t *data, size_t size) {
    if (size == 0 || xSemaphoreTake(transmitMutex, portMAX_DELAY) != pdTRUE) {
        return;
    }

    portENTER_CRITICAL(&connectionStateLock);
    const uint16_t activeConnectionHandle = connectionHandle;
    const bool canNotify = notificationsEnabled;
    portEXIT_CRITICAL(&connectionStateLock);

    if (!canNotify || activeConnectionHandle == INVALID_CONNECTION_HANDLE) {
        xSemaphoreGive(transmitMutex);
        return;
    }

    const uint16_t mtu = ble_att_mtu(activeConnectionHandle);
    const size_t maximumChunkSize = mtu > 3 ? mtu - 3 : 20;

    for (size_t offset = 0; offset < size;) {
        const size_t remaining = size - offset;
        const size_t chunkSize =
            remaining < maximumChunkSize ? remaining : maximumChunkSize;
        os_mbuf *packet = ble_hs_mbuf_from_flat(data + offset, chunkSize);
        if (packet == nullptr) {
            xSemaphoreGive(transmitMutex);
            return;
        }

        const int result = ble_gatts_notify_custom(
            activeConnectionHandle, transmitValueHandle, packet);
        if (result != 0) {
            xSemaphoreGive(transmitMutex);
            return;
        }
        offset += chunkSize;
    }
    xSemaphoreGive(transmitMutex);
}

static void sendSerialText(const char *text) {
    sendSerialBytes(
        reinterpret_cast<const uint8_t *>(text), strlen(text));
}

static void sendFormattedLine(const char *format, ...) {
    char line[96];
    va_list arguments;
    va_start(arguments, format);
    const int written = vsnprintf(line, sizeof(line), format, arguments);
    va_end(arguments);

    if (written < 0) {
        return;
    }

    const size_t textLength = static_cast<size_t>(written);
    const size_t boundedLength =
        textLength < sizeof(line) ? textLength : sizeof(line) - 1;
    sendSerialBytes(reinterpret_cast<const uint8_t *>(line), boundedLength);
    sendSerialText("\r\n");
}

static uint8_t readMotorPosition() {
    uint8_t position = 0;
    if (xSemaphoreTake(motorPositionMutex, portMAX_DELAY) == pdTRUE) {
        position = motorPosition;
        xSemaphoreGive(motorPositionMutex);
    }
    return position;
}

static uint32_t servoPulseMicrosecondsForPosition(uint8_t position) {
    return SERVO_MIN_PULSE_MICROSECONDS +
        ((static_cast<uint32_t>(position) *
          (SERVO_MAX_PULSE_MICROSECONDS - SERVO_MIN_PULSE_MICROSECONDS)) /
         255UL);
}

static uint32_t servoDutyForPosition(uint8_t position) {
    return (servoPulseMicrosecondsForPosition(position) * MOTOR_PWM_MAX_DUTY) /
        MOTOR_PWM_FRAME_MICROSECONDS;
}

static esp_err_t writeServoPosition(uint8_t position) {
    esp_err_t result = ledc_set_duty(
        MOTOR_PWM_MODE, MOTOR_PWM_CHANNEL, servoDutyForPosition(position));
    if (result != ESP_OK) {
        printf("Failed to set motor PWM duty: %s\n", esp_err_to_name(result));
        return result;
    }

    result = ledc_update_duty(MOTOR_PWM_MODE, MOTOR_PWM_CHANNEL);
    if (result != ESP_OK) {
        printf("Failed to update motor PWM duty: %s\n", esp_err_to_name(result));
    }
    return result;
}

static void printHardwareConfiguration() {
    sendSerialText("Hardware by pin:\r\n");
    sendSerialText(
        "[0] GPIO22: 50Hz PWM servo output, motorPosition 0-255 maps to 1000-2000us\r\n");
    sendSerialText("[1] GPIO2: status LED heartbeat output\r\n");
}

static void printTelemetry(uint16_t requestedId) {
    const uint8_t position = readMotorPosition();
    const uint32_t pulseMicroseconds =
        servoPulseMicrosecondsForPosition(position);

    if (requestedId == SERVO_ELEMENT_ID) {
        sendFormattedLine(
            "SERVO,%u,%lu,%u",
            static_cast<unsigned>(position),
            static_cast<unsigned long>(pulseMicroseconds),
            servoTestEnabled ? 1U : 0U);
        return;
    }

    if (requestedId == LED_ELEMENT_ID) {
        sendSerialText("LED,HEARTBEAT,1000\r\n");
        return;
    }

    sendFormattedLine(
        "MotorPosition: %u GPIO22 PWM servo pulse=%luus test=%u",
        static_cast<unsigned>(position),
        static_cast<unsigned long>(pulseMicroseconds),
        servoTestEnabled ? 1U : 0U);
}

static bool commandEquals(const char *command, const char *expected) {
    return strcmp(command, expected) == 0;
}

static bool commandStartsWith(
    const char *command, const char *prefix, const char *&remainder) {
    while (*prefix != '\0') {
        if (*command != *prefix) {
            return false;
        }
        ++command;
        ++prefix;
    }
    remainder = command;
    return true;
}

static bool parseUnsignedId(const char *text, uint16_t &value) {
    if (*text < '0' || *text > '9') {
        return false;
    }

    uint16_t result = 0U;
    while (*text >= '0' && *text <= '9') {
        result = static_cast<uint16_t>(
            result * 10U + static_cast<uint16_t>(*text - '0'));
        ++text;
    }

    if (*text != '\0') {
        return false;
    }

    value = result;
    return true;
}

static bool parseUnsignedToken(
    const char *text,
    uint16_t &value,
    const char *&afterValue) {
    if (*text < '0' || *text > '9') {
        return false;
    }

    uint16_t result = 0U;
    while (*text >= '0' && *text <= '9') {
        result = static_cast<uint16_t>(
            result * 10U + static_cast<uint16_t>(*text - '0'));
        ++text;
    }

    value = result;
    afterValue = text;
    return true;
}

static void setServoPosition(uint8_t position, bool testEnabled) {
    if (xSemaphoreTake(motorPositionMutex, portMAX_DELAY) == pdTRUE) {
        motorPosition = position;
        servoTestEnabled = testEnabled;
        writeServoPosition(motorPosition);
        xSemaphoreGive(motorPositionMutex);
    }
}

static void handleServoCommand(const char *arguments) {
    uint16_t id = 0U;
    const char *cursor = nullptr;
    if (!parseUnsignedToken(arguments, id, cursor) || *cursor != ' ') {
        sendSerialText("Usage: servo <id> <position>\r\n");
        return;
    }

    uint16_t position = 0U;
    if (!parseUnsignedId(cursor + 1, position)) {
        sendSerialText("Usage: servo <id> <position>\r\n");
        return;
    }

    if (id != SERVO_ELEMENT_ID) {
        sendSerialText("Unknown element id.\r\n");
        return;
    }

    if (position > 255U) {
        sendSerialText("Error: servo position must be 0..255.\r\n");
        return;
    }

    setServoPosition(static_cast<uint8_t>(position), false);
    sendFormattedLine(
        "Servo %u position %u.",
        static_cast<unsigned>(id),
        static_cast<unsigned>(position));
}

static void handleTestCommand(const char *arguments) {
    if (commandEquals(arguments, "off") ||
        commandEquals(arguments, "disable")) {
        if (xSemaphoreTake(motorPositionMutex, portMAX_DELAY) == pdTRUE) {
            servoTestEnabled = false;
            xSemaphoreGive(motorPositionMutex);
        }
        sendSerialText("Servo test disabled.\r\n");
        return;
    }

    if (commandEquals(arguments, "on") ||
        commandEquals(arguments, "enable")) {
        if (xSemaphoreTake(motorPositionMutex, portMAX_DELAY) == pdTRUE) {
            servoTestEnabled = true;
            xSemaphoreGive(motorPositionMutex);
        }
        sendSerialText("Servo test enabled.\r\n");
        return;
    }

    uint16_t id = 0U;
    const char *cursor = nullptr;
    if (parseUnsignedToken(arguments, id, cursor) &&
        id == SERVO_ELEMENT_ID && *cursor == ' ') {
        if (commandEquals(cursor + 1, "enable")) {
            if (xSemaphoreTake(motorPositionMutex, portMAX_DELAY) == pdTRUE) {
                servoTestEnabled = true;
                xSemaphoreGive(motorPositionMutex);
            }
            sendSerialText("Servo test enabled.\r\n");
            return;
        }
        if (commandEquals(cursor + 1, "disable") ||
            commandEquals(cursor + 1, "off")) {
            if (xSemaphoreTake(motorPositionMutex, portMAX_DELAY) == pdTRUE) {
                servoTestEnabled = false;
                xSemaphoreGive(motorPositionMutex);
            }
            sendSerialText("Servo test disabled.\r\n");
            return;
        }
    }

    sendSerialText("Usage: test off|on or test <id> enable|disable\r\n");
}

static void handleCommand(const char *command) {
    if (command[0] == '\0') {
        return;
    }

    if (commandEquals(command, "hardware")) {
        printHardwareConfiguration();
        return;
    }

    if (commandEquals(command, ".")) {
        printTelemetry(2U);
        return;
    }

    const char *idText = nullptr;
    if (commandStartsWith(command, ". ", idText)) {
        uint16_t id = 0U;
        if (parseUnsignedId(idText, id)) {
            printTelemetry(id);
        }
        else {
            sendSerialText("Usage: . [<id>]\r\n");
        }
        return;
    }

    const char *arguments = nullptr;
    if (commandStartsWith(command, "servo ", arguments)) {
        handleServoCommand(arguments);
        return;
    }

    if (commandStartsWith(command, "test ", arguments)) {
        handleTestCommand(arguments);
        return;
    }

    sendFormattedLine("Unknown command: %s", command);
}

static void processReceivedByte(uint8_t received) {
    if (received == '\r' || received == '\n') {
        commandBuffer[commandLength] = '\0';
        handleCommand(commandBuffer);
        commandLength = 0U;
        return;
    }

    if (received == '\b' || received == 127U) {
        if (commandLength > 0U) {
            --commandLength;
        }
        return;
    }

    if (received < 32U || received > 126U) {
        return;
    }

    if (commandLength + 1U < COMMAND_BUFFER_SIZE) {
        commandBuffer[commandLength++] = static_cast<char>(received);
    }
    else {
        sendSerialText("Command too long.\r\n");
        commandLength = 0U;
    }
}

static void processReceivedPacket(const uint8_t *received, uint16_t size) {
    bool hasLineEnding = false;
    for (uint16_t index = 0; index < size; ++index) {
        if (received[index] == '\r' || received[index] == '\n') {
            hasLineEnding = true;
        }
    }

    if (!hasLineEnding && commandLength == 0U && size < COMMAND_BUFFER_SIZE) {
        for (uint16_t index = 0; index < size; ++index) {
            if (received[index] < 32U || received[index] > 126U) {
                return;
            }
            commandBuffer[index] = static_cast<char>(received[index]);
        }
        commandBuffer[size] = '\0';
        handleCommand(commandBuffer);
        return;
    }

    for (uint16_t index = 0; index < size; ++index) {
        processReceivedByte(received[index]);
    }
}

static int receiveSerialData(uint16_t,
                             uint16_t,
                             ble_gatt_access_ctxt *context,
                             void *) {
    const uint16_t receivedSize = OS_MBUF_PKTLEN(context->om);
    if (receivedSize > MAX_RECEIVED_MESSAGE_SIZE) {
        return BLE_ATT_ERR_INVALID_ATTR_VALUE_LEN;
    }

    uint8_t received[MAX_RECEIVED_MESSAGE_SIZE];
    uint16_t copiedSize = receivedSize;
    const int result = ble_hs_mbuf_to_flat(
        context->om, received, sizeof(received), &copiedSize);
    if (result != 0) {
        return BLE_ATT_ERR_UNLIKELY;
    }

    for (uint16_t index = 0; index < copiedSize; ++index) {
        if (received[index] > 0x7f) {
            return BLE_ATT_ERR_UNLIKELY;
        }
    }

    processReceivedPacket(received, copiedSize);
    return 0;
}

static int accessTransmitData(uint16_t,
                              uint16_t,
                              ble_gatt_access_ctxt *,
                              void *) {
    return BLE_ATT_ERR_READ_NOT_PERMITTED;
}

static const ble_gatt_chr_def characteristics[] = {
    {
        .uuid = &SERIAL_TX_UUID.u,
        .access_cb = accessTransmitData,
        .flags = BLE_GATT_CHR_F_NOTIFY,
        .val_handle = &transmitValueHandle,
    },
    {
        .uuid = &SERIAL_RX_UUID.u,
        .access_cb = receiveSerialData,
        .flags = BLE_GATT_CHR_F_WRITE | BLE_GATT_CHR_F_WRITE_NO_RSP,
    },
    {},
};

static const ble_gatt_svc_def services[] = {
    {
        .type = BLE_GATT_SVC_TYPE_PRIMARY,
        .uuid = &SERIAL_SERVICE_UUID.u,
        .characteristics = characteristics,
    },
    {},
};

static int handleGapEvent(ble_gap_event *event, void *) {
    switch (event->type) {
        case BLE_GAP_EVENT_CONNECT:
            if (event->connect.status == 0) {
                portENTER_CRITICAL(&connectionStateLock);
                connectionHandle = event->connect.conn_handle;
                notificationsEnabled = false;
                bootMessagePending = true;
                portEXIT_CRITICAL(&connectionStateLock);
            } else {
                startAdvertising();
            }
            break;

        case BLE_GAP_EVENT_DISCONNECT:
            portENTER_CRITICAL(&connectionStateLock);
            connectionHandle = INVALID_CONNECTION_HANDLE;
            notificationsEnabled = false;
            portEXIT_CRITICAL(&connectionStateLock);
            startAdvertising();
            break;

        case BLE_GAP_EVENT_ADV_COMPLETE:
            startAdvertising();
            break;

        case BLE_GAP_EVENT_SUBSCRIBE:
            if (event->subscribe.attr_handle == transmitValueHandle) {
                portENTER_CRITICAL(&connectionStateLock);
                notificationsEnabled = event->subscribe.cur_notify != 0;
                const bool shouldSendBootMessage =
                    notificationsEnabled && bootMessagePending;
                if (shouldSendBootMessage) {
                    bootMessagePending = false;
                }
                portEXIT_CRITICAL(&connectionStateLock);
                if (shouldSendBootMessage) {
                    sendSerialText(BOOT_MESSAGE);
                }
            }
            break;

        default:
            break;
    }

    return 0;
}

static void startAdvertising() {
    ble_hs_adv_fields fields = {};
    fields.flags = BLE_HS_ADV_F_DISC_GEN | BLE_HS_ADV_F_BREDR_UNSUP;
    fields.uuids128 = const_cast<ble_uuid128_t *>(&SERIAL_SERVICE_UUID);
    fields.num_uuids128 = 1;
    fields.uuids128_is_complete = 1;

    int result = ble_gap_adv_set_fields(&fields);
    if (result != 0) {
        printf("Failed to set BLE advertising fields: %d\n", result);
        return;
    }

    ble_hs_adv_fields scanResponse = {};
    scanResponse.name = reinterpret_cast<const uint8_t *>(ADVERTISED_NAME);
    scanResponse.name_len = sizeof(ADVERTISED_NAME) - 1;
    scanResponse.name_is_complete = 0;
    result = ble_gap_adv_rsp_set_fields(&scanResponse);
    if (result != 0) {
        printf("Failed to set BLE scan response: %d\n", result);
        return;
    }

    ble_gap_adv_params parameters = {};
    parameters.conn_mode = BLE_GAP_CONN_MODE_UND;
    parameters.disc_mode = BLE_GAP_DISC_MODE_GEN;
    result = ble_gap_adv_start(ownAddressType, nullptr, BLE_HS_FOREVER,
                               &parameters, handleGapEvent, nullptr);
    if (result != 0) {
        printf("Failed to start BLE advertising: %d\n", result);
    }
}

static void onNimbleReset(int reason) {
    printf("NimBLE host reset, reason: %d\n", reason);
}

static void onNimbleSynchronized() {
    const int result = ble_hs_id_infer_auto(0, &ownAddressType);
    if (result != 0) {
        printf("Failed to determine BLE address type: %d\n", result);
        return;
    }
    startAdvertising();
}

static void runNimbleHost(void *) {
    nimble_port_run();
    nimble_port_freertos_deinit();
}

static bool configureMotorPwm() {
    ledc_timer_config_t timerConfig = {};
    timerConfig.speed_mode = MOTOR_PWM_MODE;
    timerConfig.duty_resolution = MOTOR_PWM_RESOLUTION;
    timerConfig.timer_num = MOTOR_PWM_TIMER;
    timerConfig.freq_hz = MOTOR_PWM_FREQUENCY_HZ;
    timerConfig.clk_cfg = LEDC_AUTO_CLK;
    esp_err_t result = ledc_timer_config(&timerConfig);
    if (result != ESP_OK) {
        printf("Failed to configure motor PWM timer: %s\n",
               esp_err_to_name(result));
        return false;
    }

    ledc_channel_config_t channelConfig = {};
    channelConfig.gpio_num = MOTOR_PWM_GPIO;
    channelConfig.speed_mode = MOTOR_PWM_MODE;
    channelConfig.channel = MOTOR_PWM_CHANNEL;
    channelConfig.intr_type = LEDC_INTR_DISABLE;
    channelConfig.timer_sel = MOTOR_PWM_TIMER;
    channelConfig.duty = servoDutyForPosition(motorPosition);
    channelConfig.hpoint = 0;
    result = ledc_channel_config(&channelConfig);
    if (result != ESP_OK) {
        printf("Failed to configure motor PWM channel: %s\n",
               esp_err_to_name(result));
        return false;
    }

    return true;
}
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
extern "C" void app_main() {
    printf("esp32ServoBLEController boot\n");

    motorPositionMutex = xSemaphoreCreateMutex();
    if (motorPositionMutex == nullptr) {
        printf("Failed to create motor position mutex\n");
        return;
    }

    const BaseType_t blinkTaskCreated = xTaskCreatePinnedToCore(
        blinkStatusLed, "status-led", 2048, nullptr, 4, nullptr, 0);
    if (blinkTaskCreated != pdPASS) {
        printf("Failed to create status LED task\n");
    }

    const BaseType_t motorTaskCreated = xTaskCreatePinnedToCore(
        runMotorPwmCycle, "motor-pwm", 3072, nullptr, 4, nullptr, 0);
    if (motorTaskCreated != pdPASS) {
        printf("Failed to create motor PWM task\n");
    }

    esp_err_t result = nvs_flash_init();
    if (result == ESP_ERR_NVS_NO_FREE_PAGES ||
        result == ESP_ERR_NVS_NEW_VERSION_FOUND) {
        ESP_ERROR_CHECK(nvs_flash_erase());
        result = nvs_flash_init();
    }
    ESP_ERROR_CHECK(result);
    transmitMutex = xSemaphoreCreateMutex();
    if (transmitMutex == nullptr) {
        printf("Failed to create BLE transmit mutex\n");
        return;
    }
    ESP_ERROR_CHECK(nimble_port_init());

    ble_hs_cfg.reset_cb = onNimbleReset;
    ble_hs_cfg.sync_cb = onNimbleSynchronized;

    ble_svc_gap_init();
    ble_svc_gatt_init();
    ESP_ERROR_CHECK(ble_svc_gap_device_name_set(DEVICE_NAME));
    ESP_ERROR_CHECK(ble_gatts_count_cfg(services));
    ESP_ERROR_CHECK(ble_gatts_add_svcs(services));

    nimble_port_freertos_init(runNimbleHost);
}

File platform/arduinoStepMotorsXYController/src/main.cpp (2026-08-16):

#include "AvrExternalPowerSupplyDetector.h"
#include "AvrGpioLed.h"
#include "AvrMotorDriverEnable.h"
#include "AvrStepDirectionDriver.h"
#include "AvrSystemClock.h"
#include "AvrUartSerial.h"
#include "StepperMotorProgram.h"

#include "hal/ExternalPowerSupplyDetector.h"
#include "hal/GpioLed.h"
#include "hal/MotorDriverEnable.h"
#include "hal/SystemClock.h"
#include "hal/UartSerial.h"

#include "motion/stepperMotor/StepperMotor.h"
#include "motion/stepperMotor/StepperMotorController.h"

static const uint8_t COMMAND_BUFFER_SIZE = 32U;

static const StepperMotorProgram STEPPER_MOTOR_PROGRAMS[] = {
    StepperMotorProgram(
        StepperMotor(
            BIPOLAR_STEPPER_MOTOR,
            "D42HSC4409B-23B",
            200U,
            BIPOLAR_STEPPER_MOTOR_MICROSTEP_16,
            STEPPER_MOTOR_STEP_PIN,
            STEPPER_MOTOR_DIRECTION_PIN),
        STEPPER_MOTOR_STEP_PULSE_MICROSECONDS,
        STEPPER_MOTOR_DIRECTION_SETUP_MICROSECONDS,
        STEPPER_MOTOR_TRAVEL_ROTATIONS,
        STEPPER_MOTOR_ACCELERATION_MILLISECONDS,
        STEPPER_MOTOR_CRUISE_MILLISECONDS,
        STEPPER_MOTOR_DECELERATION_MILLISECONDS,
        STEPER_MOTOR_DRIVER_TMC2209,
        StepperMotorProgram::NO_UART_PIN,
        StepperMotorProgram::NO_UART_PIN,
        false),
    StepperMotorProgram(
        StepperMotor(
            BIPOLAR_STEPPER_MOTOR,
            "D42HSC4409B-23B",
            STEPPER_MOTOR_Y_FULL_STEPS_PER_ROTATION,
            BIPOLAR_STEPPER_MOTOR_MICROSTEP_16,
            STEPPER_MOTOR_Y_STEP_PIN,
            STEPPER_MOTOR_Y_DIRECTION_PIN),
        STEPPER_MOTOR_STEP_PULSE_MICROSECONDS,
        STEPPER_MOTOR_DIRECTION_SETUP_MICROSECONDS,
        STEPPER_MOTOR_Y_TRAVEL_ROTATIONS,
        STEPPER_MOTOR_ACCELERATION_MILLISECONDS,
        STEPPER_MOTOR_CRUISE_MILLISECONDS,
        STEPPER_MOTOR_DECELERATION_MILLISECONDS,
        STEPER_MOTOR_DRIVER_TMC2209,
        StepperMotorProgram::NO_UART_PIN,
        StepperMotorProgram::NO_UART_PIN,
        STEPPER_MOTOR_Y_DIRECTION_INVERTED != 0)
};

static const uint8_t STEPPER_MOTOR_COUNT = static_cast<uint8_t>(
    sizeof(STEPPER_MOTOR_PROGRAMS) / sizeof(STEPPER_MOTOR_PROGRAMS[0]));

static_assert(
    sizeof(STEPPER_MOTOR_PROGRAMS) / sizeof(STEPPER_MOTOR_PROGRAMS[0]) <= 255U,
    "The motor registry index uses uint8_t");

static bool
hasValidAndUniquePins(uint8_t motorIndex)
{
    const StepperMotor& motor = STEPPER_MOTOR_PROGRAMS[motorIndex].motor;
    if (motor.stepPin < 2U || motor.directionPin < 2U ||
        motor.stepPin == motor.directionPin) {
        return false;
    }

    for (uint8_t i = 0U; i < motorIndex; ++i) {
        const StepperMotor& previousMotor = STEPPER_MOTOR_PROGRAMS[i].motor;
        if (motor.stepPin == previousMotor.stepPin ||
            motor.stepPin == previousMotor.directionPin ||
            motor.directionPin == previousMotor.stepPin ||
            motor.directionPin == previousMotor.directionPin) {
            return false;
        }
    }
    return true;
}

static void
printAvailableCommands(UartSerial& serial)
{
    serial.writeLine("Available commands:");
    serial.writeLine("  . [<id>]  Print telemetry, or one element with an id.");
    serial.writeLine("  device  Print this firmware device description and role.");
    serial.writeLine("  help  Show the list of available commands.");
    serial.writeLine("  hardware  List hardware elements by pin, tagged [id].");
    serial.writeLine("  get <id>  Print status of one hardware element.");
    serial.writeLine("  console enable  Enable periodic console output.");
    serial.writeLine("  console disable Disable periodic console output.");
    serial.writeLine("  test <id> enable|disable  Toggle test movement for element <id>.");
    serial.writeLine("  motordriver <id> enable|disable  Toggle the shared motor driver enable line (PSU element <id>).");
    serial.writeLine("  steps <id> <n> <speed>  Move motor <id> by n steps at speed steps/s (blocking; test must be disabled).");
}

static void
printHardwareConfiguration(UartSerial& serial)
{
    serial.writeLine("Hardware by pin:");

    for (uint8_t i = 0U; i < STEPPER_MOTOR_COUNT; ++i) {
        const StepperMotorProgram& program = STEPPER_MOTOR_PROGRAMS[i];
        const StepperMotor& motor = program.motor;

        serial.writeString("[");
        serial.writeUnsigned(i);
        serial.writeString("] D");
        serial.writeUnsigned(motor.directionPin);
        serial.writeString(", D");
        serial.writeUnsigned(motor.stepPin);
        serial.writeString(": stepper motor ");
        serial.writeUnsigned(i);
        serial.writeString(" (direction, step), ");
        serial.writeString(motor.referenceName);
        serial.writeString(" driven by ");
        serial.writeString(steperMotorDriverName(program.driver));

        if (program.uartReceivePin != StepperMotorProgram::NO_UART_PIN) {
            serial.writeString(" (UART: RX=D");
            serial.writeUnsigned(program.uartReceivePin);
            serial.writeString(", TX=D");
            serial.writeUnsigned(program.uartTransmitPin);
            serial.writeString(")");
        }
        serial.writeLine("");
    }

    serial.writeString("[");
    serial.writeUnsigned(STEPPER_MOTOR_COUNT);
    serial.writeString("] A5, D");
    serial.writeUnsigned(MOTOR_DRIVER_ENABLE_PIN);
    serial.writeString(
        ": external power supply detector input, motor driver enable");
    serial.writeLine("");
}

static void
printDeviceDescription(UartSerial& serial)
{
    serial.writeLine(
        "Device arduino ATmega2650, Role XY steper motor controller");
}

static bool
commandEquals(const char* command, const char* expected)
{
    while (*command != '\0' && *expected != '\0') {
        if (*command != *expected) {
            return false;
        }
        ++command;
        ++expected;
    }
    return *command == '\0' && *expected == '\0';
}

static bool
commandStartsWith(const char* command, const char* prefix, const char*& remainder)
{
    while (*prefix != '\0') {
        if (*command != *prefix) {
            return false;
        }
        ++command;
        ++prefix;
    }
    remainder = command;
    return true;
}

static bool
parseUnsignedId(const char* text, uint16_t& value)
{
    if (*text < '0' || *text > '9') {
        return false;
    }

    uint16_t result = 0U;
    while (*text >= '0' && *text <= '9') {
        result = static_cast<uint16_t>(
            result * 10U + static_cast<uint16_t>(*text - '0'));
        ++text;
    }
    value = result;
    return true;
}
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

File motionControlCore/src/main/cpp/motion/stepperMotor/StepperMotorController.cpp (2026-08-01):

#include "motion/stepperMotor/StepperMotorController.h"

#include "motion/stepperMotor/StepperMotorDriver.h"

StepperMotorController::StepperMotorController()
    : m_driver(nullptr),
      m_maxMilliStepsPerSecond(0),
      m_accelerationMilliseconds(0),
      m_cruiseMilliseconds(0),
      m_decelerationMilliseconds(0),
      m_profileStartMilliseconds(0),
      m_lastUpdateMilliseconds(0),
      m_stepAccumulator(0),
      m_position(0),
      m_speedMilliStepsPerSecond(0),
      m_directionForward(false),
      m_profileInitialized(false)
{
}

bool
StepperMotorController::initialize(StepperMotorDriver& driver)
{
    m_driver = &driver;
    m_directionForward = false;
    m_profileInitialized = false;
    return m_driver->initialize();
}

void
StepperMotorController::configureRepeatingTrapezoid(
    uint32_t maxMilliStepsPerSecond,
    uint16_t accelerationMilliseconds,
    uint16_t cruiseMilliseconds,
    uint16_t decelerationMilliseconds)
{
    m_maxMilliStepsPerSecond = maxMilliStepsPerSecond;
    m_accelerationMilliseconds = accelerationMilliseconds;
    m_cruiseMilliseconds = cruiseMilliseconds;
    m_decelerationMilliseconds = decelerationMilliseconds;
    m_profileStartMilliseconds = 0;
    m_lastUpdateMilliseconds = 0;
    m_stepAccumulator = 0;
    m_speedMilliStepsPerSecond = 0;
    m_directionForward = false;
    m_profileInitialized = false;
}

void
StepperMotorController::update(uint32_t nowMilliseconds, bool enabled)
{
    if (!enabled || m_driver == nullptr ||
        profileCycleDurationMilliseconds() == 0UL) {
        m_lastUpdateMilliseconds = nowMilliseconds;
        m_stepAccumulator = 0;
        m_speedMilliStepsPerSecond = 0;
        m_profileInitialized = false;
        return;
    }

    if (!m_profileInitialized) {
        m_profileStartMilliseconds = nowMilliseconds;
        m_lastUpdateMilliseconds = nowMilliseconds;
        m_stepAccumulator = 0;
        m_profileInitialized = true;
    }

    const uint32_t elapsedMilliseconds =
        nowMilliseconds - m_lastUpdateMilliseconds;
    const uint32_t cycleDurationMilliseconds =
        profileCycleDurationMilliseconds();
    uint32_t profileElapsedMilliseconds =
        m_lastUpdateMilliseconds - m_profileStartMilliseconds;
    uint32_t unprocessedMilliseconds = elapsedMilliseconds;

    while (unprocessedMilliseconds > 0UL) {
        const uint32_t cycleIndex =
            profileElapsedMilliseconds / cycleDurationMilliseconds;
        const uint32_t cycleElapsedMilliseconds =
            profileElapsedMilliseconds % cycleDurationMilliseconds;
        const uint32_t millisecondsUntilCycleEnd =
            cycleDurationMilliseconds - cycleElapsedMilliseconds;
        const uint32_t intervalMilliseconds =
            unprocessedMilliseconds < millisecondsUntilCycleEnd ?
                unprocessedMilliseconds : millisecondsUntilCycleEnd;

        setDirection((cycleIndex % 2UL) == 0UL);
        m_stepAccumulator +=
            profileIntegratedMilliStepsMilliseconds(
                cycleElapsedMilliseconds + intervalMilliseconds) -
            profileIntegratedMilliStepsMilliseconds(
                cycleElapsedMilliseconds);

        while (m_stepAccumulator >= 1000000UL) {
            m_stepAccumulator -= 1000000UL;
            emitStep();
        }

        profileElapsedMilliseconds += intervalMilliseconds;
        unprocessedMilliseconds -= intervalMilliseconds;
        if (intervalMilliseconds == millisecondsUntilCycleEnd) {
            m_stepAccumulator = 0UL;
        }
    }

    m_lastUpdateMilliseconds = nowMilliseconds;
    const uint32_t currentCycleIndex =
        profileElapsedMilliseconds / cycleDurationMilliseconds;
    const uint32_t currentCycleElapsedMilliseconds =
        profileElapsedMilliseconds % cycleDurationMilliseconds;
    setDirection((currentCycleIndex % 2UL) == 0UL);
    m_speedMilliStepsPerSecond =
        profileMilliStepsPerSecond(currentCycleElapsedMilliseconds);
}
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

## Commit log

2026-07-18 Base template for Arduino micro controller
2026-07-18 Arduino LED blink program with serial feedback working, development scripts in place
2026-07-18 Using 1Mbps serial UART speed for monitor
2026-07-18 External voltage detection and input commands support
2026-07-19 Stepper motor model
2026-07-19 Design check, generalized to support motors-platforms
2026-07-19 Testing on Arduino Uno
2026-07-25 System tested with TMC2209 motor driver in A4988 compatibility mode
2026-07-25 Preparing architecture to support several different motor drivers
2026-07-25 Documentation update: Fritzing diagrams
    [testbed.fzz]
2026-07-26 Interactive console clean
    [testbedUartMode.fzz]
2026-08-01 Control per motor by steps and with interactive console
2026-08-01 PSU propertly updated at interactive console
    [testbed.fzz]
2026-08-01 UART using interrupts instead of pooling and supporting again 1000000 bauds
2026-08-02 Arduino circuitry changed to be compatible with CNC Shield V3
    [testbed.fzz, testbedUartMode.fzz]
2026-08-02 PSU element models motor driver enable pin control
    [testbed.fzz]
2026-08-03 Power supply using A5 pin
    [testbed.fzz]
2026-08-16 Simple motor connections compatible with Arduino CNC Shield 3.0
    [testbed.fzz]
2026-08-16 Two equal motors setup in firmware
2026-08-16 Interactive console is multithread, one thread per device
2026-08-23 ESP-32 controller accepting BLE commands to control servo
2026-08-23 Interactive console supports multiple devices
